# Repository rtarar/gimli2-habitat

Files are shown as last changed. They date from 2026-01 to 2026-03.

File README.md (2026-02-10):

# Gimli2 — Expedition Truck + Habitat Program

Gimli2 is an expedition-truck build program to create a durable, long-duration overland platform optimized for full-time living and remote work. The base vehicle is a Mercedes-Benz 1225 AF (NG80 chassis), being converted into a self-supported global-travel rig with an integrated habitat module (approximately 16 ft). The objective is a vehicle that can reliably handle corrugations, poor roads, and mixed climates while remaining serviceable, safe, and practical for extended international travel.

This repository documents the end-to-end systems engineering of the truck + habitat: structural/subframe integration, entry systems, cabinetry and interior construction, water/grey tanks and plumbing, thermal/heating (diesel/hydronic), and a 24V Victron-based electrical architecture with a large LiFePO₄ bank and a roof solar array (on the order of ~1.2 kW) to support off-grid living. The build is managed with disciplined governance (canonical artifacts, decision logs, and versioning) to prevent design drift across tools, vendors, and iterations—and to preserve a high-quality record suitable for future publication.

---

## What We’re Building

- **Base vehicle:** Mercedes-Benz 1225 AF (NG80 chassis)
- **Habitat module:** ~16 ft expedition habitat for full-time living + remote work
- **Primary design goals:** reliability, serviceability, off-grid autonomy, safety, and documentation completeness
- **Core systems in scope:**
  - Structure & integration (subframe, pass-through, reinforcements)
  - Electrical (24V Victron ecosystem, LiFePO₄ bank, solar, monitoring)
  - Plumbing (fresh + grey, filtration, pumps, winterization considerations)
  - Thermal (diesel/hydronic heating strategy; insulation approach)
  - Interior (cabinetry materials, mounting strategy, durability on corrugations)
  - Security & networking (as required for remote work and travel)

---

## How This Repo Is Organized

This repo is designed so newcomers can understand the project, and contributors can make changes without causing “design drift.”

- `docs/specs/` — Requirements, constraints, acceptance criteria, design targets
- `docs/architecture/` — System architecture, schematics, interface-control notes
- `docs/decisions/` — Decision log / ADR-style records (what we chose and why)
- `docs/vendor/` — Vendor comms, quotes, procurement decisions, lead times
- `cad/` — CAD exports (STEP/DXF), profiles, reference geometry
- `build-log/` — Build log entries, photos/notes, “what changed in the real world”

> The enforceable rules for how changes are proposed and recorded live in `PROJECT_CONSTITUTION.md`.

---

## Working Agreements (High Level)

- Major design choices must be recorded in the decision log before they are treated as “real.”
- Drawings and specs must carry a version and “Last updated” date when modified.
- Unknowns are explicitly marked `TBD` with an owner/action to resolve them.

---

## Habitat Floor Plan

**Key dimensions:**
- Interior: 4780mm (L) × 2280mm (W) × 2160mm (H)
- Kitchen: ~2300mm length × 600mm depth (**passenger side**)
- Floor-to-ceiling cabinets opposite kitchen (**driver side**)
- Bathroom: toilet on **driver side** (below WIN-04), shower on **passenger side**
- Entry door (DOOR-01): **passenger side**, adjacent to shower area
- Kitchen window (WIN-05): **passenger side**, in kitchen zone
- Bathroom window (WIN-04): **driver side**, above toilet
- Garage shell: wall-to-wall (2280mm), 860mm high, with exterior hatches on both sides
- U-shaped dinette with rear bench seating on garage shell top

### Top View — Day Mode (Bed Raised)

Floor Plan - Top View

### Side Elevation — Passenger Side (Looking Toward Driver)

Side Elevation View

### Layout Summary

| Element | Location | Notes |
|---|---|---|
| **Kitchen** | Passenger side | Behind bathroom, with WIN-05 window |
| **Floor-to-ceiling cabinets** | Driver side | Opposite kitchen |
| **Toilet** | Driver side (bathroom) | Below WIN-04 window |
| **Shower** | Passenger side (bathroom) | Adjacent to entry door |
| **Entry door (DOOR-01)** | Passenger side | Opens into bathroom/shower area |
| **WIN-04** | Driver side | Bathroom window above toilet |
| **WIN-05** | Passenger side | Kitchen window |
| **Bedside cabinets (lower)** | Both sides | 300mm deep × **660mm long** (ends where WIN-01/WIN-02 start) |
| **Bedside cabinets (upper)** | Both sides | 300mm deep × 2000mm long (above window level) |

### Bedside Cabinet Structure (ZONE-007)

The bedside storage cabinets are split into three vertical zones to avoid blocking the rear windows:

| Zone | Height Range | Depth | Description |
|---|---|---|---|
| **Lower** | 0–860mm | 660mm | Bulk storage, ends where windows start |
| **Window** | 860–1435mm | — | No cabinet (window clearance for WIN-01/WIN-02) |
| **Upper** | 1435–2160mm | 2000mm | Full bed length, above window level |

**Window clearance calculation:**
- WIN-01/WIN-02 centers: 1200mm from rear wall, width 1063mm
- Window rear edge: 1200 - 531.5 = **668.5mm** from rear
- Lower cabinet depth: **660mm** (8.5mm clearance from window)

### Interactive 3D Viewer

To explore the habitat in 3D, you can host this repository on GitHub Pages or view it locally.

**View Online (GitHub Pages):**
1. Go to repository **Settings** > **Pages**.
2. Select `main` branch as the source and save.
3. Your viewer will be live at: `https://rtarar.github.io/gimli2-habitat/renders/habitat_zones_3d.html`

**View Locally:**
Open the HTML file in your browser:
```bash
open renders/habitat_zones_3d.html
```

The 3D viewer includes:
- All functional zones (color-coded)
- Day/Night mode toggle (shows bed raised vs lowered)
- Wireframe view option
- Windows, doors, and hatches
- **Click zones** to highlight and identify them.

---

## Current Status (Update as Needed)

- [ ] Baseline architecture and subsystem boundaries captured
- [ ] Electrical one-line and parts list stabilized (24V Victron)
- [ ] Plumbing and tank layout finalized (fresh/grey, filtration, winterization)
- [ ] Thermal/insulation strategy selected and documented
- [ ] Entry and exterior integration decisions (steps/ladder, carriers, hatches)
- [ ] Interior cabinetry material and mounting strategy confirmed

---

## Contributing

If you want to contribute, open an issue describing:
1) the problem or improvement,
2) the affected subsystem(s),
3) the tradeoffs you see,
4) any links to relevant artifacts (specs, drawings, vendor data).

Proposed changes that impact architecture, safety, or procurement should include a decision entry in `docs/decisions/`.

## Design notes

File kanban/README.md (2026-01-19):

# Kanban Workflow

This directory manages work prioritization and tracking for the Gimli2 Habitat project.

## Board Structure

Work items flow through these stages:

```
BACKLOG → READY → IN_PROGRESS → REVIEW → DONE
```

### Stage Definitions

| Stage | Description |
|---|---|
| BACKLOG | Identified work, not yet prioritized |
| READY | Prioritized, dependencies resolved, ready to start |
| IN_PROGRESS | Actively being worked on |
| REVIEW | Work complete, awaiting validation/approval |
| DONE | Validated, approved, and archived |

## File Organization

```
kanban/
├── README.md           # This file
├── backlog.yml         # Items in BACKLOG
├── ready.yml           # Items READY to start
├── in-progress.yml     # Items IN_PROGRESS
├── review.yml          # Items in REVIEW
├── done/               # Archived completed items
│   └── YYYY-MM/        # Organized by month
└── templates/
    └── work-item.yml   # Template for new items
```

## Work Item Schema

Each work item follows this structure:

```yaml
- id: WI-001
  title: Short descriptive title
  type: requirement | design | validation | documentation
  description: |
    Detailed description of the work
  created: YYYY-MM-DD
  created_by: name
  priority: critical | high | medium | low
  dependencies:
    - WI-000  # Must complete first
  blocks:
    - WI-002  # Cannot start until this completes
  requirements:
    - REQ-001  # Related requirements
  decisions:
    - DEC-001  # Related decisions
  assigned_to: null | name
  status: backlog | ready | in_progress | review | done
  notes: |
    Additional context
```

## Rules

### Adding Items

1. New items start in BACKLOG
2. Include all known dependencies
3. Reference related requirements/decisions
4. AI agents may propose items (status: PROPOSED)

### Moving Items

1. Items move forward only (no regression without documentation)
2. Cannot move to READY if dependencies unresolved
3. Cannot move to DONE without review approval
4. Log all status changes with timestamp and reason

### Priority Definitions

| Priority | Definition |
|---|---|
| CRITICAL | Blocks all other work, must resolve immediately |
| HIGH | Important for current milestone |
| MEDIUM | Should complete this iteration |
| LOW | Nice to have, can defer |

### Dependencies

- Dependencies must be explicit
- Cannot start work with unresolved dependencies
- Circular dependencies are forbidden (see GOVERNANCE.md)
- AI agents must check dependencies before proposing actions

## Metrics (Future)

Track for continuous improvement:
- Cycle time per item type
- Blocked time
- Throughput per week
- Dependency chains length

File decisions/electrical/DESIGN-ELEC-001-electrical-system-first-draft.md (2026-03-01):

# Electrical System Design — First Draft

**ID:** DESIGN-ELEC-001
**Version:** 0.3 (Updated with alternator, heater, CPAP, Starlink decisions)
**Date:** 2026-02-28
**Status:** DRAFT — Pending Owner Review
**Resolves:** DECISIONS-ELEC-001 (Sections A–F) + REVIEW-ELEC-001 (Findings #1–#10)

---

## 0. Design Basis & Assumptions

**Design locale:** Southeast USA (primary); worldwide expedition (secondary).
**Autonomy target:** 10 days without shore power or engine charging.
**Cooking strategy:** Indoor electric when weather is poor; outdoor propane kitchen when weather permits. Load scenarios modelled as "Heavy" (all-electric cooking) and "Conservation" (propane cooking, minimal AC loads).
**Bus voltage:** 24 V DC (DECIDED 2026-02-28).
**Battery chemistry:** LiFePO4 (Victron NG series).
**Ecosystem:** Victron throughout for integration, international parts availability, and Cerbo GX monitoring.
**Generator backup:** Diesel generator in rear storage box, driver side (DECIDED 2026-02-28).
**Wiring standard:** ABYC E-11 marine-grade throughout (DECIDED 2026-02-28).
**Charge sources (4):** Solar array, alternator DC-DC, shore power, diesel generator.

---

## 1. Battery Bank (B3, B9 — DECIDED)

**Selection:** 4 × Victron Lithium NG 25.6V / 300Ah, connected in parallel.

| Parameter | Value |
|---|---|
| Nominal voltage | 25.6 V |
| Total capacity | 1,200 Ah |
| Total energy | 30.7 kWh |
| Usable energy (95% DoD) | 29.2 kWh |
| Max continuous discharge | 1,200 A (4 × 300A) |
| Dimensions per unit | 841 × 206 × 205 mm (L × H × D) |
| Weight per unit | 52 kg |
| Total battery weight | 208 kg |
| BMS required | Lynx Smart BMS NG 1000A |

### 1.1 Fitment Verification (Updated)

The original CONFLICT-001 resolution assumed 6 modules at 540 × 250 × 220 mm, totalling 300 kg. The new selection is 4 × NG 25.6V/300Ah — significantly different geometry but **92 kg lighter**.

**Proposed arrangement:** 2 × 2 stack (2 across depth, 2 high) in the Passenger-Side Kitchen Base, above the water tank toe-kick extension.

| Dimension | Required (with 25mm clearance) | Available | Status |
|---|---|---|---|
| Depth | 485 mm (2 × 205 + 3 × 25) | 600 mm | FITS |
| Height | 487 mm (2 × 206 + 3 × 25) | ~600 mm (above 200mm tank) | FITS |
| Length | 891 mm (841 + 2 × 25) | Along habitat axis | FITS |

**Mass balance impact:** 208 kg at Z ≈ +800 (forward of axle) continues to serve as counterweight to the rear water/structure mass. The 92 kg weight reduction vs. original assumption improves the overall mass budget.

**Action required:** Confirm the 891mm length along the habitat axis does not conflict with adjacent cabinetry or the water tank extension footprint.

---

## 2. Appliance Selections (Section A)

### A1 — Induction Cooktop (2-Burner)

**Recommended:** Camplux RIH602BF or equivalent 2-burner, 120V / 1800W shared power.

| Parameter | Value |
|---|---|
| Rated power | 1800 W (shared between burners) |
| Surge | ~2200 W (momentary at startup) |
| Voltage | 120 V AC / 15A circuit |
| Mounting | Built-in or countertop |

**Notes:** 1800W shared means both burners cannot run at full power simultaneously — one operates at reduced output. This is standard for RV 15A circuits. For heavy Indian cooking with two pots, expect to stagger burners or use mid-power settings. The outdoor propane kitchen handles overflow.

### A2 — Convection Microwave / Oven / Air Fryer Combo

**Status: OPEN — Research required.**

No final decision has been recorded on this appliance. Options to evaluate:

1. **Convection microwave only** (e.g., Sharp R1874T, ~1500W input) — proven RV choice, compact.
2. **Microwave + air fryer combo** (e.g., Toshiba ML2-EC10SA, Galanz GSWWA16BKSA10) — adds air-frying without a separate appliance.
3. **Dedicated air fryer + separate microwave** — better at each task but takes two slots/circuits.

**Placeholder for load table:** Using 1,500W input / 1,800W surge until model is selected.

| Parameter | Value (placeholder) |
|---|---|
| Input power | ~1,500 W |
| Surge | ~1,800 W |
| Voltage | 120 V AC / dedicated 15A circuit |

**Action required:** Owner to research combo units and decide. Key criteria: 120V operation, ≤1500W input, fits RV cutout dimensions, available internationally (or easy to replace).

### A3 — Roof Fans (× 2)

**Recommended:** MaxxFan Deluxe 7000K (with remote control + thermostat).

| Parameter | Value |
|---|---|
| Voltage | 12 V DC (requires 24V→12V converter) |
| Current draw | 0.2 A (low) to 2.66 A (max) per unit |
| Average draw (mid speed) | ~1.3 A per unit at 12V ≈ 16W each |
| Total for 2 units | ~32 W average |

### A4 — Washer

**Recommended:** Compact portable washer, shore-power only.

| Parameter | Value |
|---|---|
| NA market | 120V unit (Comfee or equivalent, ~300W) |
| International | 230V unit for European/Indian shore power |
| Operation | Shore-only (per REQ-ELEC-001 §7.2) |

**Strategy:** Carry one 120V unit for NA, or source a universal-voltage compact washer. The 230V outlet (Section F) on shore power handles international camping. This appliance is excluded from the battery load table.

### A5 — Fridge / Freezer (DECIDED)

**Selected:** Vitrifrigo SLIM250 CHR HP, Black.

| Parameter | Value |
|---|---|
| Total capacity | 250 L (two compartments: upper front-opening + lower drawer) |
| Voltage | 12/24 V DC and 115/230 V AC |
| Rated power | 75 W |
| Compressor | NextGen R600a (high performance, 3 kg lighter than standard) |
| Dimensions | 595 mm (W) × 651 mm (D) × 1,550 mm (H) |
| Weight | ~59 kg |
| Daily consumption (est.) | ~900–1,200 Wh/day (75W × 50–65% duty cycle) |

**Notes:** The SLIM250 is a significantly larger unit than the C115i originally considered. The 75W rated power with duty cycling in hot SE USA conditions could push daily consumption to ~1,200 Wh/day. This is a meaningful increase in the load table. The unit should run on 24V DC directly to avoid inverter losses. Confirm 24V DC operation from the SLIM250 specs.

### A6 — Separate Freezer

**Not required.** The SLIM250 has a dedicated lower freezer drawer compartment, providing ample frozen storage for expedition provisioning.

### A7 — Starlink (DECIDED)

**Selected:** Starlink Standard (flat dish, Gen 3).

| Parameter | Value |
|---|---|
| Active power | 50–75 W |
| Idle/standby | ~20 W |
| Daily consumption (16h active / 8h idle) | ~960–1,360 Wh |
| Voltage | Proprietary PoE, 48V from router brick |

**Notes:** Starlink is the single largest continuous DC load. Schedule Starlink sleep mode overnight to save ~160 Wh/night. The load table uses 960 Wh/day (16h active at 60W average).

### A8 — Router

**Recommended:** Pepwave MAX BR1 Pro 5G.

| Parameter | Value |
|---|---|
| Nominal power | 8 W |
| Max power | 19 W |
| Average | 12 W |
| Input | 12 V DC |
| Daily consumption | ~288 Wh |

### A9 — CPAP (DECIDED)

**Selected:** ResMed AirSense 10 (primary, with humidifier) + ResMed AirMini (travel/backup).

#### AirSense 10 (Primary — with Humidifier)

| Parameter | Value |
|---|---|
| Power supply | 24V DC / 90W rated |
| Typical power (with humidifier, no heated tube) | ~30–53 W |
| Peak power (with heated tube + humidifier) | ~70–104 W |
| Nightly consumption (8 hrs, humidifier on) | ~240–420 Wh |
| Input | 24V DC (native — matches bus voltage directly) |

#### AirMini (Travel / Backup)

| Parameter | Value |
|---|---|
| Typical power | ~6.3 W |
| Peak power | 27 W |
| Nightly consumption (8 hrs) | ~50–70 Wh |
| Input | 24V DC (native) |

**Notes:** Both units run natively on 24V DC, matching the bus voltage — no inverter needed. The AirSense 10 with humidifier is the heavier load (~240–420 Wh/night depending on heated tube setting). Use a direct 24V DC cable adapter for both. The AirMini uses waterless humidification (HumidX cartridge) and draws significantly less power, making it ideal for deep off-grid nights when power is scarce or as backup if the AirSense 10 develops issues.

**Load table impact:** Using AirSense 10 with humidifier at mid-range (~330 Wh/night) as the baseline. This is a meaningful increase from the original 72 Wh estimate (AirSense 11 without humidifier).

### A10 — UV Water Filter

**Recommended:** Viqua S2Q-P/12VDC.

| Parameter | Value |
|---|---|
| Power | 17 W |
| Flow rate | 3 GPM |
| Voltage | 12 V DC |
| Daily consumption | ~4 Wh (on-demand only) |

---

## 2B. Additional Systems (Electrical Load Inputs)

### Diesel Heater — Webasto ThermaPro 90 (DECIDED)

The habitat will use a Webasto ThermaPro 90 external diesel heater with heat exchanger, tapping into the engine coolant circuit. A future hydronic heating solution for the habitat interior will be integrated later.

| Parameter | Value |
|---|---|
| Heat output | Up to 9.1 kW |
| Fuel | Diesel (0.2–0.9 L/hr) |
| Electrical consumption | 37–83 W (operating range), 110 W max |
| Voltage | 24V DC (CONFIRMED) |
| Operating temp range | −40 to +80°C |

**Electrical impact:** When running, the ThermaPro 90 draws 37–83W from the DC bus. In cold-weather camping (heater running 12+ hrs/day), this adds 450–1,000 Wh/day to the load table. Added as a winter-use line item.

### Water Cabinet — Integrated Pump + Accumulator (DECIDED)

The water system will use a MotorCraft (or equivalent) integrated water cabinet solution combining the pump, accumulator, and associated plumbing components in a single pre-assembled unit.

**Electrical impact:** The integrated pump unit replaces the separate pump line items in the load table. Typical draw: 60W when running, intermittent duty cycle (~30 min/day total). ~30 Wh/day.

**Action required:** Confirm exact brand/model and power specifications for the water cabinet. The "MotorCraft" name did not return results — may be a different brand (Whale, Truma, Fiamma?). Please confirm.

---

## 3. Load Table (B1)

### 3.1 AC Loads (Through Inverter)

| Load | W (cont) | W (surge) | Heavy Wh/day | Conservation Wh/day |
|---|---|---|---|---|
| Induction cooktop | 1,800 | 2,200 | 2,935 | 0 |
| Convection microwave | 1,500 | 1,800 | 815 | 0 |
| Instapot | 1,000 | 1,200 | 815 | 0 |
| Blender/grinder | 500 | 1,200 | 54 | 0 |
| TV/monitor | 60 | 80 | 196 | 130 |
| Laptop charging ×2 | 130 | 130 | 565 | 424 |
| Phone/tablet charging | 30 | 30 | 98 | 65 |
| Heat pad | 60 | 60 | 130 | 65 |
| Vacuum | 400 | 600 | 65 | 43 |
| **AC subtotal (at battery, 92% inv eff)** | | | **5,674** | **728** |

### 3.2 DC Loads (Direct from Bus)

| Load | W (cont) | W (surge) | Heavy Wh/day | Conservation Wh/day |
|---|---|---|---|---|
| Fridge/freezer (SLIM250) | 45 | 75 | 1,080 | 1,080 |
| Starlink Standard | 60 | 100 | 960 | 480 |
| Pepwave BR1 Pro 5G | 12 | 19 | 288 | 288 |
| MaxxFan ×2 | 32 | 64 | 384 | 256 |
| Interior lighting (all) | 50 | 100 | 300 | 200 |
| Cabinet/drawer lights | 5 | 15 | 5 | 2 |
| Water pump (internal) | 60 | 120 | 30 | 18 |
| Water pump (stream intake) | 80 | 150 | 20 | 0 |
| UV water filter | 17 | 17 | 4 | 3 |
| Cameras ×4 | 12 | 16 | 288 | 288 |
| NVR | 10 | 15 | 240 | 240 |
| IR emitters ×6 | 12 | 18 | 120 | 120 |
| CPAP (AirSense 10 + humidifier) | 40 | 104 | 330 | 330 |
| Camera/drone/GoPro charging | 50 | 50 | 100 | 25 |
| Toothbrush/shaver charging | 10 | 10 | 20 | 10 |
| Lynx BMS + Cerbo GX | 15 | 20 | 360 | 360 |
| ThermaPro 90 diesel heater (24V) | 60 | 110 | 0 | 0 |
| *(ThermaPro winter use: add 720 Wh/day when heating 12 hrs)* | | | | |
| **DC subtotal** | | | **4,529** | **3,700** |

### 3.3 Daily Totals

| Scenario | AC (Wh) | DC (Wh) | Losses (Wh) | Total (Wh) | Total (kWh) |
|---|---|---|---|---|---|
| **Heavy cooking day** | 5,674 | 4,529 | 200 | **10,403** | **10.4** |
| **Conservation mode** | 728 | 3,700 | 200 | **4,628** | **4.6** |
| **Conservation + winter heating** | 728 | 4,420 | 200 | **5,348** | **5.3** |

**Note on v0.3 changes:** AirSense 10 with humidifier adds ~258 Wh/day vs original no-humidifier estimate (72 → 330 Wh/night). Starlink Standard retained. The SLIM250 fridge (1,080 Wh/day) remains the dominant baseline load at ~23% of conservation demand.

---

## 4. Daily Demand & Autonomy Analysis (B2)

### 4.1 Autonomy Without Solar

| Scenario | Daily demand | Battery autonomy (29.2 kWh usable) |
|---|---|---|
| Heavy cooking | 10.4 kWh | 2.8 days |
| Conservation (propane) | 4.6 kWh | 6.3 days |
| Conservation + winter heating | 5.3 kWh | 5.5 days |

### 4.2 Key Finding — 10-Day Target

With the SLIM250 fridge, Starlink Standard, and AirSense 10 with humidifier, the 10-day no-solar target requires active energy management. At 4.6 kWh/day conservation mode, pure battery provides 6.3 days.

**Realistic scenario analysis:**

1. **Even overcast days produce solar:** At just 1 peak sun hour (heavy cloud), the 2050W array produces ~1.7 kWh/day, reducing the net drain to ~2.9 kWh/day → **10.0 days autonomy**.
2. **Starlink scheduling:** Reducing Starlink to 8 hours/day saves ~480 Wh/day → brings conservation demand to ~4.1 kWh/day → **7.1 days** pure battery, **12+ days** with minimal solar.
3. **CPAP fallback:** Switching from AirSense 10 (330 Wh/night) to AirMini (60 Wh/night) saves ~270 Wh/night — significant savings for deep off-grid stretches.
4. **Driving days:** 4 hours of engine charging adds 3.2 kWh via DC-DC chargers, nearly offsetting a full conservation day.
5. **Fridge eco-mode:** If the SLIM250 duty cycle can be reduced (cooler ambient, less door opening), consumption could drop to ~800 Wh/day, saving ~280 Wh/day.

**Realistic assessment:** The system achieves 10+ days off-grid in scenarios with minimal solar (even heavy overcast). In true zero-input scenarios (dense forest canopy, no driving), expect 6–7 days. The AirMini provides a meaningful power-saving fallback for extended off-grid. A 5th battery (+7.7 kWh, +52 kg) would push pure-battery conservation to ~8.0 days. The 10-day absolute-zero-input target may warrant the 5th battery — owner decision.

**With generator (DECIDED):** The Fischer Panda 4000s Neo eliminates the autonomy concern entirely. A 4-hour generator run charges ~10 kWh, covering 2+ days of conservation-mode demand. With the 500L diesel tank, the generator provides 500+ hours of runtime — effectively unlimited electrical autonomy regardless of solar conditions. The 10-day target is comfortably met even in zero-solar scenarios.

**Recommendation:** Start with 4 batteries. The generator provides the safety net. A 5th battery is no longer needed for autonomy — only consider it if real-world data shows you want to reduce generator run frequency.

---

## 5. Inverter / Charger (B4, B5, F1)

**Recommended:** Victron MultiPlus-II 24/5000/120-95.

| Parameter | Value |
|---|---|
| Continuous output | 4,000 W |
| Surge output (5 sec) | 9,000 W |
| AC output | 120 V / 60 Hz |
| Built-in charger | 120 A @ 24V = 2,880 W from shore |
| AC input range | 90–140 V (handles weak shore power) |
| Dimensions | 627 × 350 × 150 mm |
| Weight | 29 kg |

### 5.1 Peak Load Headroom

| Scenario | Load (W) | Inverter capacity | Headroom |
|---|---|---|---|
| Realistic peak (cooking + TV + laptop) | 1,990 | 4,000 W | 2,010 W |
| Worst case (induction + microwave) | 3,300 | 4,000 W | 700 W |
| Absolute max (cooking + Instapot) | 3,500 | 4,000 W | 500 W |

### 5.2 Dual-Voltage / International Strategy (F1)

**Decision: Single inverter/charger, field-switchable.**

The MultiPlus-II can be reconfigured between 120V/60Hz and 230V/50Hz output via software (VictronConnect). For world travel:

1. **NA mode:** 120V/60Hz output, 120V shore input — standard configuration.
2. **International mode:** Reflash to 230V/50Hz output, 230V shore input.
3. **Shore inlet:** Install a dual-standard inlet with adaptor kit (NEMA 14-50 for NA, CEE17 blue 32A for international). The MultiPlus-II's wide input range handles both.

This avoids carrying two inverters and saves ~29 kg + significant cabinet space. The trade-off is that 120V NA appliances need a step-down transformer when running in 230V mode overseas, but this only matters for the cooktop and microwave (all other loads run on DC).

**Alternative (if dual simultaneous output needed):** Add a Victron Autotransformer for split-phase or step-down functionality.

### 5.3 Washer Circuit (F2)

The washer runs shore-only. Provide a dedicated 230V/16A outlet wired directly from the shore input bus, bypassing the inverter. An interlock relay ensures this outlet is only live when shore power is connected. For NA, use the MultiPlus's AC-2 output (unswitched pass-through).

### 5.4 Additional 230V Outlet (F3)

One additional 230V general outlet in the utility zone, also on the shore-only bus. Useful for hair dryers, power tools, or other occasional high-draw appliances at campsites.

---

## 6. Solar Array (B6)

### 6.1 Panel Selection

**Recommended:** 5 × 410W monocrystalline panels (generic high-quality, e.g., Trina, JA Solar, or similar).

| Parameter | Value |
|---|---|
| Panel dimensions | 1,722 × 1,134 × 30 mm |
| Weight per panel | 21.5 kg |
| Total array | 2,050 W |
| Total weight | 107.5 kg |

### 6.2 Roof Layout

Roof area: 4,750 × 2,280 mm (10.8 m²).

**Layout:** 4 panels in 2×2 portrait grid (occupying 3,444 × 2,268 mm at the forward section), plus 1 panel in landscape orientation (1,134 × 1,722 mm) offset. Remaining roof area (~1,300 × 2,280 mm at the rear) accommodates 2× MaxxFan roof vents, Starlink dish mount, and the consolidated cable penetration.

### 6.3 Solar Production by Location

| Location | Peak Sun Hours | Net Production (kWh/day) |
|---|---|---|
| SE USA (summer) | 5.5 | 9.2 |
| SE USA (winter) | 3.5 | 5.9 |
| SE USA (annual avg) | 4.5 | 7.6 |
| Northern Europe (summer) | 4.0 | 6.7 |
| Northern Europe (winter) | 1.5 | 2.5 |
| India (annual avg) | 5.0 | 8.4 |
| Overcast / cloudy | 1.0 | 1.7 |

(Net = gross × 0.82 system efficiency factor for MPPT efficiency, cable losses, temperature derating, and dust/soiling.)

### 6.4 Net Energy Balance (Updated for SLIM250 Fridge)

| Scenario | Demand | Solar | Net drain | Battery days |
|---|---|---|---|---|
| Heavy cooking, SE USA avg | 10.4 kWh | 7.6 kWh | +2.8 kWh | 10.4 days |
| Heavy cooking, no sun | 10.4 kWh | 0 | +10.4 kWh | 2.8 days |
| Conservation, SE USA avg | 4.6 kWh | 7.6 kWh | −3.0 kWh | ∞ (net charge) |
| Conservation, no sun | 4.6 kWh | 0 | +4.6 kWh | 6.3 days |
| Conservation, cloudy (1 PSH) | 4.6 kWh | 1.7 kWh | +2.9 kWh | 10.0 days |
| Conservation + winter heat, SE USA | 5.3 kWh | 7.6 kWh | −2.3 kWh | ∞ (net charge) |

**Conclusion:** In SE USA with average sun, the solar array fully covers all scenarios including winter heating. The system is solar-positive for conservation and near break-even for heavy cooking. The CPAP with humidifier adds ~258 Wh/night vs the original estimate; the AirMini backup provides a meaningful off-grid power-saving fallback. The SLIM250 fridge remains the dominant baseline load.

### 6.5 MPPT Controller

**Recommended:** Victron SmartSolar MPPT 250/100 VE.Can.

| Parameter | Value |
|---|---|
| Max PV power (at 24V) | 2,900 W (headroom for 2,050W array) |
| Max charge current | 100 A |
| Max PV Voc | 250 V |
| String config | 5S1P (cold Voc ~209V, within limit) or 2S2P + 1 |

**Preferred string configuration:** 5 panels in series (5S1P). This keeps the array current low (~13A) reducing cable losses, and the cold-weather Voc (~209V at −10°C) stays safely within the 250V controller limit. Higher voltage also improves MPPT efficiency at low light levels.

---

## 7. Alternator Charging (B10) — DECIDED

**Selected:** 2 × Victron Orion-Tr Smart 24/24-17A (isolated), wired in parallel.

| Parameter | Value |
|---|---|
| Truck alternator | 24V / 110A (CONFIRMED) |
| Per unit | 17A continuous / 400W |
| Combined output | 34A / 800W |
| Daily charge (4 hrs driving) | 3.2 kWh |

**Notes:** The truck alternator is confirmed as 24V / 110A. The 34A combined draw from the two Orion-Tr units represents ~31% of the alternator's rated capacity — well within safe continuous loading (typically 70–80% of rated output). The Orion-Tr Smart has engine-detection logic, adaptive 3-stage charging, and Bluetooth monitoring. Two units in parallel provide redundancy — if one fails, the other continues charging at 400W.

For trucks with smart alternators or Euro 6 emissions alternators, the Orion-Tr's current-limiting protects the alternator.

---

## 7B. Diesel Generator — DECIDED

**Selected:** Fischer Panda 4000s Neo PMS (AC output version).

| Parameter | Value |
|---|---|
| Continuous output | 3.0 kW (3.6 kVA) |
| Max output | 3.4 kW (4.0 kVA) |
| Voltage | 230V / 50Hz (also configurable for 120V / 60Hz) |
| Engine | Fischer Panda single-cylinder diesel, water-cooled |
| Cooling | Double-circuit freshwater heat exchanger + air-cooled radiator |
| Noise | 54 dB(A) at 7m (whisper-quiet, conversational volume) |
| Dimensions | 558 × 460 × 518 mm (L × W × H) |
| Weight (dry) | 92 kg |
| Fuel consumption | 0.6–1.2 L/hr |
| Fuel source | Tapped from main truck diesel tank |

**Location:** Rear storage box, driver side, behind rear storage. Compartment minimum: 733 × 635 × 568 mm (including service clearances and vibration mount gaps).

**Integration:** Generator AC output connects to the shore power input bus via a changeover relay. The MultiPlus-II auto-detects AC input and begins charging at up to 2,880W (120A @ 24V). Auto-start via Cerbo GX relay: triggers at 25% SOC, stops at 85% SOC.

**Installation details:** Vibration-isolated mounts (Fischer Panda OEM kit), 3mm steel reinforcement plate on box floor, marine-grade wet exhaust routed to rear/underside, fuel tap with anti-siphon valve and dedicated filter, air-cooled radiator with 12V fan for heat rejection. Compartment lined with 25mm closed-cell acoustic foam (mass-loaded vinyl backed). CO detector mandatory inside habitat.

**Charge time from generator:**

| Battery state | Time to 90% SOC |
|---|---|
| From 20% (emergency) | ~8.5 hours |
| From 50% (typical top-up) | ~4.7 hours |
| From 70% (light top-up) | ~2.4 hours |

**Why Fischer Panda:** OEM supplier for Unicat, Action Mobil, and military expedition platforms. International marine dealer network covers most port cities worldwide. Water-cooled design allows sealed compartment (no air vents for engine cooling). 54 dB at 7m is roughly 4× quieter perceived than the Onan QD 3200 alternative (72 dB at 3m).

See [DESIGN-ELEC-002-generator-selection.md](DESIGN-ELEC-002-generator-selection.md) for full comparison of evaluated models and detailed installation specifications.

---

## 8. DC Distribution (B8)

### 8.1 Bus Architecture

```
[Battery Bank 24V] → [Lynx Smart BMS NG 1000A] → [Lynx Distributor]
                                                         │
                    ┌────────────────────────────────────┤
                    │            │            │           │
              [MultiPlus-II] [MPPT 250/100] [DC-DC ×2] [DC Bus]
              (Inverter/Chgr) (Solar)       (Alternator)   │
                    │                                      │
    ┌───────────────┤                            ┌────────┤────────┐
    │               │                            │        │        │
[AC Input Bus] [AC Panel]                  [24V Loads] [24→12V ×2] [24→48V]
    │     │                                            Converters  (Starlink)
    │     │                                               │
[Shore] [Fischer Panda]                              [12V Loads]
 Power   Generator                            (Split: critical / non-critical)
         (Auto-start via Cerbo)
```

### 8.2 24V Direct Loads

Loads that can run directly on the 24V bus (or have 24V versions available): CPAP (AirSense 10 + AirMini, both native 24V), Cerbo GX, Lynx BMS, ThermaPro 90 heater (24V confirmed), some LED drivers.

### 8.3 12V Loads (via 24V→12V DC-DC Converter)

Most RV appliances run on 12V: fridge, fans, water pump, cameras, NVR, lighting, UV filter, router. Dual Victron Orion 24/12-25 (300W each) non-isolated converters provide the 12V rail with redundancy (see §13.5 and Finding #7).

| 12V Load | Draw (A at 12V) |
|---|---|
| Fridge (SLIM250) | 3.75 avg, 6.25 surge |
| MaxxFan ×2 | 2.6 avg, 5.3 max |
| Water pump | 5 avg, 10 surge |
| Lighting | 4.2 avg |
| Cameras + NVR | 1.8 |
| IR emitters | 1.0 |
| UV filter | 1.4 (intermittent) |
| Router | 1.0 |
| Misc charging | 3.0 |
| ThermaPro 90 heater | 2.5 avg, 4.6 max |
| **Total 12V** | **~24 A avg, ~38 A peak** |

**Dual converter configuration (redundancy — per REVIEW-ELEC-001 Finding #7):**

| Converter | Loads | Rating |
|---|---|---|
| **Converter A (Critical)** — Orion 24/12-25 | Fridge, water pump, interior lighting, BMS/Cerbo | 25A / 300W |
| **Converter B (Non-critical)** — Orion 24/12-25 | Fans, cameras, NVR, IR emitters, charging, heater | 25A / 300W |

If one converter fails, critical loads (fridge, pump, lights) continue on the surviving unit. Non-critical loads can be manually reconnected via a crossover switch.

### 8.4 Starlink Power (DECIDED)

Starlink Standard uses a proprietary 48V PoE feed from its router/power brick. The power brick runs on 100–240V AC. Feed from the MultiPlus-II AC output (simplest approach). A 24V→48V PoE injector could improve efficiency by avoiding inverter losses — consider as a future optimisation if Starlink power draw becomes a concern.

### 8.5 DC Fuse / Breaker Sizing

All DC circuits protected via Mega fuses (high current) or standard blade fuses (branch circuits), housed in a Lynx Distributor or Victron fuse block.

| Circuit | Fuse (A) | Wire gauge |
|---|---|---|
| Battery → BMS | 300A class-T | 4/0 AWG (short run) |
| BMS → Lynx Distributor | 300A MEGA | 4/0 AWG |
| Distributor → MultiPlus-II | 250A MEGA | 2/0 AWG |
| Distributor → MPPT | 100A MEGA | 4 AWG |
| Distributor → DC-DC (alt) | 40A | 8 AWG |
| Distributor → 12V converter | 30A | 10 AWG |
| 12V branch circuits | 5–15A blade fuses | 14–10 AWG |

---

## 9. AC Distribution (B7)

### 9.1 Branch Circuit Plan

| Circuit # | Load | Breaker | Wire | Notes |
|---|---|---|---|---|
| AC-1 | Induction cooktop | 20A / 120V | 12 AWG | Dedicated |
| AC-2 | Convection microwave | 15A / 120V | 14 AWG | Dedicated |
| AC-3 | Kitchen duplex (Instapot, blender) | 15A / 120V | 14 AWG | GFCI protected |
| AC-4 | Sitting area outlets (L + R) | 15A / 120V | 14 AWG | GFCI protected |
| AC-5 | Electronics charging drawer | 15A / 120V | 14 AWG | |
| AC-6 | Medicine cabinet + vacuum + misc | 15A / 120V | 14 AWG | |
| AC-7 | Exterior outlets (3 locations) | 20A / 120V | 12 AWG | GFCI + weatherproof |
| AC-8 | Starlink power brick | 15A / 120V | 14 AWG | Always-on (inverter output) |
| SHORE-1 | Washer (230V) | 16A / 230V | 2.5mm² | Shore-only, interlocked |
| SHORE-2 | General 230V outlet | 16A / 230V | 2.5mm² | Shore-only |

### 9.2 GFCI / AFCI Zones

All circuits serving countertop outlets, bathroom, and exterior locations are GFCI protected (per NEC for NA; equivalent RCD for international). AFCI on bedroom/sleeping area circuits if required by local code.

### 9.3 AC Panel Location

Compact RV breaker panel located adjacent to the MultiPlus-II in the Passenger Kitchen Base electrical compartment. Accessible for maintenance but not visible in the living space.

---

## 10. Switching & Control Architecture (Section C)

### C1 — Ambient Lighting Controller

**Recommended:** Victron Cerbo GX + Bluetooth LED controllers (e.g., Shelly RGBW2 or equivalent 12V RGBW LED dimmer).

The Cerbo GX provides the central hub. Individual zone LED controllers communicate via Bluetooth or Modbus for integration. Each zone has its own RGBW controller for independent dimming and colour selection (warm white / red / blue stealth modes).

**Zones:**
1. Entry + Bathroom — 1× controller
2. Kitchen + Hall — 1× controller
3. Sleeping + Sitting — 1× controller (or split into 2 for bed/sitting independence)

### C2 — Cabinet / Drawer Lighting

**Method:** Magnetic reed switches (door-triggered). Simple, reliable, no digital controller needed. Each cabinet/drawer has a surface-mount reed switch wired to a local LED strip. Power from the 12V rail via the nearest lighting zone.

### C3 — Master Ambient Switch Wiring

**Method:** Smart switch bus via Shelly or equivalent WiFi/Bluetooth relay modules at each of the 3 master switch locations (cab pass-through, main entry, bed area). Each switch sends a "scene" command to all zone controllers simultaneously.

Physical fallback: A latching relay in each zone allows the master switch to work even if the smart bus is down. Belt-and-suspenders reliability for an expedition rig.

### C4 — Bluetooth / App Control

**Platform:** VictronConnect + Cerbo GX with VRM portal. The Cerbo GX already provides app-based monitoring of all Victron equipment (battery, inverter, solar, charger). Lighting control via the smart switch modules can be accessed through a dedicated lighting app (e.g., Shelly app) or integrated via Node-RED on the Cerbo.

No KNX or complex home automation. Keep it simple and debuggable on the road.

### C5 — Bed Day/Night Mode

**Method:** Manual rocker switch at the bed position. Toggles between day-mode (under-bed ambient for sitting area) and night-mode (ceiling low-level ambient + bed reading lights active). A bed-position sensor is a nice-to-have but adds complexity and a failure point. Manual switch is more reliable for expedition use.

---

## 11. Placement & Layout (Section D)

### D1 — Kitchen Duplex Outlet

Position on the backsplash wall between the cooktop and sink, centred at countertop height (~1050mm from floor). Accessible for Instapot and blender use without cord draping over the cooktop.

### D2 — Sitting Area Outlets

One duplex each side, positioned at armrest height (~600mm from floor) on the side walls. Primary charge stations for laptops, phones, and tablets.

### D3 — Medicine Cabinet Charging

4 × USB-C outlets (PD capable) inside the medicine cabinet. USB-C handles toothbrushes, shavers, and modern chargers. No USB-A needed — all modern devices are USB-C or have USB-C cables.

### D4 — Vacuum Charging Outlet

Standard 120V outlet inside the pantry or tall storage cabinet near the entry. The vacuum lives in this cabinet, always docked and charging.

### D5 — Electronics Charging Drawer

Dedicated drawer in the cabinetry adjacent to the sitting area, fitted with a 4-outlet power strip inside. Passive ventilation via slots in the drawer rear panel (warm air rises out). Houses camera chargers, drone batteries, GoPros.

### D6 — Exterior Outlets (3 locations)

| Position | Type | Notes |
|---|---|---|
| Outdoor kitchen box (passenger) | 120V / 20A GFCI, weatherproof | Feeds outdoor blender, induction |
| Passenger rear | 120V / 20A GFCI, weatherproof | Near rear storage |
| Driver rear | 120V / 20A GFCI, weatherproof | Near tool/grill access |

All exterior outlets on a dedicated circuit (AC-7) with in-use weatherproof covers (bubble type).

### D7 — Shore Power Inlet

**Side:** Passenger side (same side as electrical compartment — shortest cable run to MultiPlus-II).
**Connector:** Combination inlet box with NEMA 14-50 (NA, 50A) and CEE17 blue (international, 32A). Adaptor cables for smaller connections (30A TT-30, standard 15A).

### D8 — Roof Penetration & Conduit

Single consolidated roof penetration near the rear of the solar array zone. Uses a marine-grade deck gland or Renogy entry plate for multiple cable pass-throughs (solar, Starlink). Conduit routes internally along the ceiling channel to the battery/electrical zone in the kitchen base.

---

## 12. Exterior Lighting (Section E)

### E1/E2 — Rock Lights

**Recommended:** 6 × RGBW LED rock lights (e.g., Sunpie or Xprite RGBW).

| Position | Count |
|---|---|
| Front (L + R) | 2 |
| Mid (L + R) | 2 |
| Rear (L + R) | 2 |

Built-in blue mode via RGBW controller. Single Bluetooth RGBW controller for all 6 lights, mounted in the DC distribution area. Manual on/off via a dedicated rocker switch + app control for colour selection.

### E3 — Front Security Floods

**Recommended:** 4 × round LED flood lamps (retro-style, per REQ-ELEC-001). Each 20–30W, warm white. Mounted on the front face of the habitat shell, 2 per side of centre.

### E4 — Side Floods

2 × high-mount LED floods (1 per side), mounted on the upper habitat GRP wall using non-penetrating adhesive mounts or bracket-to-extrusion clamps. Each 30–50W.

### E5 — Rear Flood

1 × LED flood bar mounted on the rear wall or box lid hinge support. 40–60W, covers rear perimeter.

### E6 — IR Emitters

6 × 850nm IR LED emitters positioned to cover the camera FOVs at each perimeter position. Each ~2W. Wired into the security circuit (always powered when security mode is active).

### E7 — Awning Light

Hardwired 12V connection point at the awning mounting rail. A waterproof 2-pin plug allows the awning light (user's choice of LED strip or fixture) to connect without permanent installation.

### Exterior Lighting Control

All exterior lights controlled via a dedicated rocker switch panel near the main entry door:

| Switch | Lights |
|---|---|
| Rock lights | All 6 (RGBW controller) |
| Security floods | All front, side, rear floods |
| IR night vision | All IR emitters |
| Awning | Awning light |

A "full perimeter" master button activates floods + IR simultaneously.

---

## 13. Expedition Hardening (per REVIEW-ELEC-001)

The following measures are adopted from the expedition manufacturer review to bring this design to production-grade standards.

### 13.1 Wiring Construction Standard — ABYC E-11 Marine Grade (Finding #3)

All electrical wiring in the habitat adopts the ABYC E-11 marine electrical standard:

| Requirement | Specification |
|---|---|
| Wire type | Tinned copper, marine-grade stranded, XLPE or TXL insulation rated 105°C minimum |
| Terminations | Adhesive-lined heat-shrink crimp terminals only. No bare crimps, no twist-and-tape. |
| Connectors | Deutsch DT/DTP series (IP67, vibration-rated) for all multi-pin connections. No Molex or spade terminals in vibration-exposed locations. |
| Loom construction | Adel clamps (cushioned P-clips) at max 300mm intervals. No cable ties as primary restraint. Split corrugated conduit or woven loom tape for protection. |
| Labelling | Every wire labelled at both ends with permanent heat-shrink labels (Brady or equivalent). |

### 13.2 Galvanic Isolator (Finding #4)

**Added:** Victron VDI-32 Galvanic Isolator installed in series with the shore power ground conductor at the inlet. Blocks low-voltage DC galvanic currents between chassis and international shore power grounds while passing AC fault currents for safety. Weight: 0.5 kg, cost: ~$100.

### 13.3 Battery Thermal Management (Finding #5)

The Victron NG LFP batteries cannot charge below 5°C (BMS lockout). The following measures ensure cold-climate operation:

| Measure | Detail |
|---|---|
| Insulated compartment | 25mm closed-cell foam on all six sides of the battery bay |
| Heating pads | 4× self-regulating 24V heating pads (one per battery), ~20W each = 80W total when active |
| BMS integration | Lynx Smart BMS NG has a dedicated heating relay output — pads activate automatically based on battery temperature sensor |
| Passive warming | Diesel heater coolant loop routed near (not through) battery compartment for ambient warming |

### 13.4 Surge Protection (Finding #6)

| Location | Device | Purpose |
|---|---|---|
| Solar input (before MPPT) | Type 2 SPD (e.g., Victron SPD Kit) | Lightning-induced surges from rooftop array |
| Shore power input | Type 2 SPD on AC input | Voltage spikes from international shore power |
| DC bus (after distributor) | DC SPD | Transient protection for sensitive electronics |

Total cost: ~$200–400. Weight: negligible (~1 kg total).

### 13.5 Inverter Redundancy (Finding #2)

**Decision:** Carry a pre-wired spare MultiPlus-II 24/5000 in storage. The spare has a pre-made cable harness (battery leads, AC output leads) with labelled connectors for rapid field swap. Estimated swap time: 30–45 minutes with basic tools. Weight: 29 kg (stored). Cost: ~$2,500.

### 13.6 Solar Panel Mounting (Finding #8)

| Requirement | Specification |
|---|---|
| Mount type | Z-bracket or L-bracket with rubber isolation pads (vibration dampening) |
| Attachment | Through-bolted to roof rails or structural aluminium extrusion. No adhesive-only mounting. |
| Air gap | 25–50mm between panel and roof for cooling (panel efficiency drops ~0.4%/°C above 25°C) |
| Edge protection | Sacrificial aluminium angle around panel perimeter to absorb branch impacts |
| Rating | Must survive continuous corrugated road vibration and 130+ km/h wind loads |

### 13.7 Load Shedding / Critical Load Priority (Finding #9)

The Cerbo GX controls programmable relay outputs to disconnect load groups based on battery SOC:

| SOC Threshold | Action |
|---|---|
| < 40% | **Warning** — Cerbo GX alert to VRM app + audible buzzer |
| < 30% | **Shed Tier 1** — Disconnect non-essential AC loads (TV, charging drawer, vacuum) via relay |
| < 20% | **Shed Tier 2** — Disconnect Starlink, exterior lighting, non-critical 12V converter |
| < 15% | **Shed Tier 3** — Only critical loads remain: fridge, water pump, interior emergency lighting, cameras, BMS |
| < 10% | **Generator auto-start** (if enabled) — Fischer Panda starts automatically |
| < 5% | **BMS disconnect** — Lynx Smart BMS disconnects all loads to protect batteries |

**Emergency lighting:** A dedicated 12V LED strip in the entry and bathroom wired on the last-disconnect circuit. Always on until the BMS physically opens the contactor.

### 13.8 Shore Power Cable Storage (Finding #10)

Dedicated exterior storage compartment (or section of the rear garage bay) for shore power cables and adaptors. Cable inventory for world travel:

| Cable / Adaptor | Region |
|---|---|
| NEMA 14-50 (50A) shore cord | North America |
| NEMA TT-30 (30A) adaptor | NA campgrounds |
| CEE17 blue 32A cord | Europe |
| CEE17 blue 16A adaptor | EU campgrounds |
| Indian 3-pin adaptor | India / South Asia |
| AU/NZ adaptor | Australia / New Zealand |
| South African 3-pin adaptor | Southern Africa |
| 25m extension cord | Universal |

All cables labelled with country/standard. Hook-and-coil storage to prevent tangles.

---

## 14. System Weight Budget

| Component | Weight (kg) | Location |
|---|---|---|
| **Core Electrical** | | |
| Batteries (4× NG 25.6V/300Ah) | 208.0 | Passenger kitchen base |
| Lynx Smart BMS NG 1000A | 5.0 | Adjacent to batteries |
| MultiPlus-II 24/5000 (active) | 29.0 | Passenger kitchen base |
| MultiPlus-II 24/5000 (spare) | 29.0 | Stored (garage/under bench) |
| SmartSolar MPPT 250/100 | 4.5 | Passenger kitchen base |
| Orion-Tr Smart DC-DC ×2 (alternator) | 3.4 | Passenger kitchen base |
| Orion 24/12-25 ×2 (12V converters) | 2.0 | DC distribution area |
| Cerbo GX + GX Touch 50 | 1.5 | Accessible panel |
| **Solar** | | |
| Solar panels (5× 410W) | 107.5 | Roof |
| Solar mounting (Z-brackets, edge guards) | 5.0 | Roof |
| **Generator** | | |
| Fischer Panda 4000s Neo PMS | 92.0 | Rear storage box, driver side |
| Generator mounting (plate, isolators) | 8.0 | Rear storage box |
| Generator cooling (radiator, hoses, fluid) | 5.0 | Rear storage box |
| Generator exhaust system | 3.0 | Rear underside |
| Generator fuel lines + filter | 2.0 | Rear to main tank |
| Generator wiring + changeover relay | 2.0 | Rear to passenger side |
| Generator compartment acoustic treatment | 3.0 | Rear storage box |
| **Expedition Hardening** | | |
| Galvanic isolator (VDI-32) | 0.5 | Shore inlet |
| Battery heating pads (×4) + insulation | 2.0 | Battery compartment |
| Surge protection (SPDs ×3) | 1.0 | Solar/shore/DC bus |
| **Distribution & Wiring** | | |
| Cabling (marine-grade tinned copper) | 28.0 | Throughout |
| DC distribution (Lynx Distributor, busbars, fuses) | 8.0 | Passenger kitchen base |
| AC distribution (breakers, panel) | 5.0 | Passenger kitchen base |
| Misc (Deutsch connectors, Adel clamps, conduit) | 12.0 | Throughout |
| **TOTAL** | **~566** | |

**Weight breakdown by zone:**

| Zone | Weight (kg) |
|---|---|
| Passenger kitchen base (batteries + electronics) | ~293 |
| Roof (solar) | ~113 |
| Rear driver side (generator) | ~115 |
| Distributed (cabling, distribution) | ~45 |

---

## 15. Full Bill of Materials

### Victron Components

| Item | Model | Qty | Role |
|---|---|---|---|
| Battery | Victron Lithium NG 25.6V/300Ah | 4 | Energy storage |
| BMS | Lynx Smart BMS NG 1000A | 1 | Battery management |
| Inverter/Charger (active) | MultiPlus-II 24/5000/120-95 | 1 | AC power + shore charging |
| Inverter/Charger (spare) | MultiPlus-II 24/5000/120-95 | 1 | Pre-wired field-swap spare |
| Solar MPPT | SmartSolar MPPT 250/100 VE.Can | 1 | Solar charge control |
| DC-DC Charger (alternator) | Orion-Tr Smart 24/24-17A (isolated) | 2 | Alternator charging |
| 24→12V Converter (critical loads) | Orion 24/12-25 (non-isolated) | 1 | Fridge, pump, lights |
| 24→12V Converter (non-critical loads) | Orion 24/12-25 (non-isolated) | 1 | Fans, cameras, charging |
| DC Distribution | Lynx Distributor | 1 | Main DC bus |
| System Monitor | Cerbo GX + GX Touch 50 | 1 | Central monitoring + app + auto-start |
| Galvanic Isolator | VDI-32 | 1 | Shore power ground protection |
| Solar Panel | 410W Monocrystalline (Trina/JA Solar) | 5 | Solar generation |

### Non-Victron Components

| Item | Model | Qty | Role |
|---|---|---|---|
| Generator | Fischer Panda 4000s Neo PMS | 1 | Backup charging (3.0–3.4 kW diesel) |
| Surge protector (solar) | Type 2 SPD (Phoenix Contact or equiv.) | 1 | Lightning/surge on PV input |
| Surge protector (shore) | Type 2 SPD | 1 | Shore power transient protection |
| Surge protector (DC bus) | DC SPD | 1 | Battery bus transient protection |
| Battery heating pads | 24V self-regulating, 20W each | 4 | Cold-climate charge enable |
| CO detector | Marine-rated CO alarm | 1 | Generator compartment safety |

---

## 16. Decisions Made This Session (2026-02-28)

| # | Decision | Resolution |
|---|---|---|
| B3 | Battery bank size | 4 × Victron NG 25.6V/300Ah = 1,200 Ah / 30.7 kWh |
| B9 | Bus voltage | 24 V DC |
| B10 | Truck alternator | 24V / 110A confirmed — Orion-Tr Smart 24/24-17A ×2 validated |
| — | Generator | Fischer Panda 4000s Neo PMS, rear storage box driver side |
| — | Wiring standard | ABYC E-11 marine-grade throughout |
| — | Galvanic isolator | Victron VDI-32 on shore power ground |
| — | Battery thermal | Heating pads + insulated compartment |
| — | Surge protection | SPDs on solar, shore, DC bus |
| — | Inverter redundancy | Carry pre-wired spare MultiPlus-II |
| — | 12V converter redundancy | Dual Orion 24/12-25 (critical/non-critical split) |
| — | Load shedding | Cerbo GX relay groups with SOC thresholds |
| — | Solar mounting | Vibration-rated Z-bracket with edge guards |
| — | ThermaPro 90 voltage | 24V version confirmed |
| A7 | Starlink | Starlink Standard (flat dish Gen 3, 50–75W, 48V PoE) |
| A9 | CPAP | AirSense 10 with humidifier (primary) + AirMini (travel/backup) |

## 17. Remaining Open Items

*Items resolved in v0.3: ~~#2 Alternator voltage~~ (24V/110A confirmed), ~~#5 ThermaPro 90 voltage~~ (24V confirmed), ~~#7 CPAP~~ (AirSense 10 + humidifier + AirMini), ~~#9 Starlink model~~ (Standard selected).*

| # | Item | Impact | Urgency |
|---|---|---|---|
| 1 | Confirm 891mm battery length fits kitchen base layout along habitat axis | Fitment | HIGH |
| 2 | **Research convection microwave / air fryer combo** — no decision recorded yet | Appliance selection (A2) | HIGH |
| 3 | **Confirm water cabinet brand/model** — "MotorCraft" not found; clarify exact product | Plumbing/electrical interface | MEDIUM |
| 4 | Verify SLIM250 actual daily consumption (75W rated; duty cycle TBD) | Load table accuracy | MEDIUM |
| 5 | Select specific exterior light fixtures | Mounting details | LOW |
| 6 | Confirm washer voltage strategy (single 120V unit or dual) | Shore circuit | LOW |
| 7 | Review smart switch platform preference (Shelly, ESP32, other) | Controls | MEDIUM |
| 8 | Define hydronic heating distribution plan for habitat interior (future, ties to ThermoPro 90) | HVAC design | LOW (future phase) |
| 9 | Confirm Fischer Panda cooling method: standalone radiator vs auxiliary truck cooling | Generator install | MEDIUM |
| 10 | Decide generator auto-start via Cerbo (yes/no) | Convenience vs complexity | LOW |

---

## 18. Related Files

- [REQ-ELEC-001-electrical-requirements.md](REQ-ELEC-001-electrical-requirements.md) — Full requirements
- [DECISIONS-ELEC-001-open-decisions.md](DECISIONS-ELEC-001-open-decisions.md) — Decision tracker
- [DESIGN-ELEC-002-generator-selection.md](DESIGN-ELEC-002-generator-selection.md) — Generator selection + installation details
- [REVIEW-ELEC-001-expedition-manufacturer-perspective.md](REVIEW-ELEC-001-expedition-manufacturer-perspective.md) — Expedition review (Unicat/Bliss Mobil/EarthRoamer perspective)
- [PLAN-electrical-layout.md](PLAN-electrical-layout.md) — Battery + inverter placement
- [CONFLICT-001-battery-fitment.md](../conflicts/CONFLICT-001-battery-fitment.md) — Battery fitment resolution
- [CONFLICT-002-water-tank-fitment.md](../conflicts/CONFLICT-002-water-tank-fitment.md) — Water tank resolution

---

*v0.1 generated 2026-02-28. v0.2 updated same day with generator decision (Fischer Panda 4000s Neo), expedition hardening measures (ABYC E-11 wiring, galvanic isolation, battery thermal, surge protection, inverter/converter redundancy, load shedding, solar mounting). v0.3 updated same day with: truck alternator confirmed 24V/110A, ThermoPro 90 confirmed 24V, CPAP decided (AirSense 10 + humidifier primary + AirMini travel/backup), Starlink Standard selected. Load table and autonomy recalculated (CPAP humidifier adds ~258 Wh/night). Open items reduced from 14 to 10. All calculations verified programmatically. Wiring gauges and fuse sizes are preliminary — final validation required during detailed electrical engineering.*

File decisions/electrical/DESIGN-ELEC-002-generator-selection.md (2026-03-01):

# Generator Selection & Installation — Gimli2 Habitat

**ID:** DESIGN-ELEC-002
**Date:** 2026-02-28
**Status:** DRAFT — Pending Owner Review
**Resolves:** REVIEW-ELEC-001 Finding #1 (No backup charge source)
**Location:** Rear storage box area, driver side, behind rear storage

---

## 1. Sizing — How Big Does It Need to Be?

### 1.1 What the Generator Must Cover

The generator serves two roles — they have very different power requirements:

**Role A — Battery bank charging (primary use, 90% of runtime):**
The generator feeds the MultiPlus-II's built-in charger, which draws up to 2,880W from shore/generator AC input (120A × 24V). This is the main use case: park in jungle, run the generator for 3–4 hours, top up the batteries, shut down.

**Role B — Simultaneous charging + light AC loads:**
While charging batteries, you might also want to run the fridge on AC, charge laptops, and run lighting. This adds ~500W on top of the charger load.

| Use Case | Power Required |
|---|---|
| Battery charging only (MultiPlus charger) | 2,880 W |
| Charging + light AC loads | ~3,400 W |
| Charging + cooking (induction) | ~4,700 W (unlikely use case) |

### 1.2 Recommended Generator Size

**Minimum: 3.0 kW continuous.**
**Sweet spot: 3.5–4.0 kW continuous.**

At 3.5 kW, the generator comfortably runs the MultiPlus charger at full rate while handling background AC loads. You'd never need to cook on the generator (that's what the propane outdoor kitchen is for), so the 4.7 kW cooking scenario is irrelevant.

A 3.5 kW generator charging the 30.7 kWh battery bank at ~2.5 kW net (accounting for charger efficiency):

| Battery State | Charge Time to 90% |
|---|---|
| From 20% (emergency) | ~8.5 hours |
| From 50% (typical top-up) | ~4.7 hours |
| From 70% (light top-up) | ~2.4 hours |

---

## 2. Generator Comparison

### 2.1 The Contenders

I've evaluated five generators across two categories: purpose-built vehicle/marine units (premium, whisper-quiet) and conventional RV generators (proven, more affordable).

---

#### TIER 1 — Premium Whisper-Quiet (Expedition Grade)

**A. Fischer Panda Panda 4000s Neo PMS**

| Parameter | Value |
|---|---|
| Continuous output | 3.0 kW (3.6 kVA) |
| Max output | 3.4 kW (4.0 kVA) |
| Voltage | 230V / 50Hz (also available 120V / 60Hz) |
| Engine | Fischer Panda single-cylinder diesel, water-cooled |
| Cooling | Double-circuit freshwater heat exchanger |
| Noise | **54 dB(A) at 7m** |
| Dimensions | 558 × 460 × 518 mm (L × W × H) |
| Weight (dry) | **92 kg** |
| Fuel consumption | 0.6–1.2 L/hr |
| Key feature | "Supersilenced" — fully encapsulated, vibration-isolated |

**Verdict:** The gold standard for expedition vehicles. This is what Unicat specs. Water-cooled means no air vents needed in the compartment. 54 dB at 7m is conversational volume — you can run it at a campsite without annoying neighbours. The 230V output works directly with the MultiPlus-II in international mode; for NA, the MultiPlus accepts 120V or 230V input.

---

**B. Fischer Panda AGT-DC 4000 24V**

| Parameter | Value |
|---|---|
| Continuous output | 3.2 kW DC |
| Max output | 4.0 kW DC |
| Output | **24V DC direct** (no inverter/charger needed!) |
| Engine | Kubota diesel, water-cooled, variable speed |
| Noise | **54 dB(A) at 7m** |
| Dimensions | ~550 × 450 × 520 mm (estimated) |
| Weight (dry) | **90–142 kg** (depends on configuration) |
| Fuel consumption | 0.5–1.0 L/hr |
| Key feature | DC output charges batteries directly, bypassing the inverter/charger entirely |

**Verdict:** The most elegant solution for a 24V battery bank. The AGT-DC outputs 24V DC directly to the battery bus, eliminating the AC→charger conversion step. Higher efficiency, simpler integration, and the generator's variable-speed controller manages the charge profile. However, it's more expensive and niche — harder to find parts internationally. The Victron Lynx BMS would need to coordinate with the AGT's charge controller.

---

**C. WhisperPower Piccolo 4**

| Parameter | Value |
|---|---|
| Continuous output | 3.5 kW |
| Voltage | 120V or 230V options |
| Noise | **< 55 dB(A)** |
| Weight | **68 kg (150 lbs)** |
| Key feature | Lightest in class, compact diesel |

**Verdict:** Excellent weight-to-power ratio. 68 kg is significantly lighter than the Fischer Panda (92 kg). Similar noise levels. Good choice if weight is the primary concern. WhisperPower has a solid marine dealer network but less expedition-vehicle presence than Fischer Panda.

---

#### TIER 2 — Proven RV Generators (Value)

**D. Cummins Onan QD 3200**

| Parameter | Value |
|---|---|
| Continuous output | 3.2 kW |
| Voltage | 120V / 60Hz |
| Engine | 347cc single-cylinder diesel, air-cooled |
| Noise | **72 dB(A) at 3m** (~60 dB(A) at 50ft — meets National Park requirements) |
| Dimensions | 767 × 440 × 457 mm (L × W × H) |
| Weight | **93 kg (205 lbs)** |
| Fuel consumption | 0.3–0.7 L/hr |
| Key feature | Industry standard RV generator, massive dealer/parts network, runs from vehicle fuel tank |

**Verdict:** The workhorse choice. Every RV dealer in North America stocks Onan parts. Air-cooled means simpler installation (no coolant plumbing) but louder than water-cooled units. At 72 dB at 3m it's noticeably louder than the Fischer Panda (54 dB at 7m — that's roughly 4× louder perceived). 120V only — needs the MultiPlus to be in NA mode, or a step-up transformer internationally.

---

**E. Dometic TEC 29** (Petrol — included for reference)

| Parameter | Value |
|---|---|
| Continuous output | 2.6 kW |
| Voltage | 230V / 50Hz |
| Engine | Honda GX160 **petrol** (not diesel) |
| Noise | **54 dB(A) at 7m** |
| Dimensions | 480 × 385 × 290 mm |
| Weight | **44 kg** |
| Key feature | Extremely compact, under-floor mounting, lightest option |

**Verdict:** The lightest and most compact option by far at only 44 kg. However, it runs on **petrol, not diesel** — meaning you'd need to carry a separate fuel supply. For an expedition truck running diesel everywhere, this is a significant logistics downside. The 2.6 kW output is also marginal for the MultiPlus charger at full rate. Included for completeness but not recommended for a diesel expedition rig.

---

### 2.2 Comparison Matrix

| Feature | Fischer Panda 4000s Neo | Fischer Panda AGT-DC 4000 | WhisperPower Piccolo 4 | Onan QD 3200 | Dometic TEC 29 |
|---|---|---|---|---|---|
| **Output** | 3.0–3.4 kW AC | 3.2–4.0 kW DC | 3.5 kW AC | 3.2 kW AC | 2.6 kW AC |
| **Fuel** | Diesel | Diesel | Diesel | Diesel | **Petrol** |
| **Cooling** | Water | Water | Water | **Air** | Air |
| **Noise (7m)** | 54 dB(A) | 54 dB(A) | <55 dB(A) | ~62 dB(A)* | 54 dB(A) |
| **Weight** | 92 kg | 90–142 kg | **68 kg** | 93 kg | **44 kg** |
| **Dimensions (LWH mm)** | 558×460×518 | ~550×450×520 | ~500×400×480 | 767×440×457 | 480×385×290 |
| **Fuel from main tank** | Yes | Yes | Yes | Yes | **No (petrol)** |
| **International parts** | Good (marine network) | Niche | Good (marine) | **Excellent (NA)** | Good (EU) |
| **Integration with 24V bus** | Via MultiPlus charger | **Direct DC — best** | Via MultiPlus charger | Via MultiPlus charger | Via MultiPlus charger |
| **Vibration isolation** | Excellent | Excellent | Good | Good | Good |
| **Est. price** | $8,000–12,000 | $10,000–15,000 | $6,000–9,000 | **$4,000–5,000** | $3,000–4,000 |

*Onan noise estimated at 7m from the 3m spec using inverse-square law.

---

## 3. Recommendation

### Primary Recommendation: Fischer Panda 4000s Neo PMS

**Why:**

1. **Whisper-quiet at 54 dB.** You can run this at a campsite, in a national park, or at 2am in a parking lot without drawing attention. The Onan at 72 dB is roughly 4× louder to the human ear.

2. **Water-cooled = sealed compartment.** No air vents needed in the storage box — the heat exchanger rejects heat through coolant. This keeps dust, rain, and insects out of the generator compartment.

3. **Diesel from the main tank.** One fuel system for the truck, heater, and generator. No carrying petrol.

4. **Right-sized at 3.0–3.4 kW.** Covers the MultiPlus charger at full rate with a little headroom.

5. **Expedition pedigree.** Fischer Panda is the OEM generator supplier for Unicat, Action Mobil, and numerous military expedition platforms. International marine dealer network means you can get service in most port cities worldwide.

**Trade-offs:** It's the second-heaviest option at 92 kg (vs 68 kg for the WhisperPower Piccolo 4), and the most expensive at $8,000–12,000. The water-cooling system adds plumbing complexity (coolant loop, raw-water intake or air-cooled radiator for vehicle installation).

### Alternative: WhisperPower Piccolo 4

If weight is critical (24 kg lighter) and budget matters, the Piccolo 4 delivers similar performance and noise levels at lower cost. It's a legitimate choice — just less proven in the expedition vehicle world than Fischer Panda.

### Budget Alternative: Cummins Onan QD 3200

If you're starting in North America and the noise difference is acceptable, the Onan is half the price with the best parts network on the continent. Consider this if the rig will spend most of its life in NA campgrounds where generator hours are common.

---

## 4. Installation — Rear Storage Box, Driver Side

### 4.1 Space Requirements

The Fischer Panda 4000s Neo needs 558 × 460 × 518 mm plus service clearances:

| Requirement | Dimension |
|---|---|
| Generator footprint | 558 × 460 mm |
| Service clearance (one side) | +150 mm |
| Exhaust routing | +100 mm rear |
| Vibration mount clearance | +25 mm all sides |
| **Total compartment minimum** | **733 × 635 × 568 mm** |

### 4.2 Mounting

1. **Vibration isolation mounts.** Fischer Panda supplies their own isolation mount kit. The generator bolts to 4× rubber-isolated mounting studs secured to a steel plate welded or bolted to the storage box floor. This is critical — diesel generator vibration will destroy the GRP shell and cabinetry if hard-mounted.

2. **Weight reinforcement.** 92 kg concentrated in the rear storage box needs structural reinforcement of the box floor. A 3mm steel plate spanning the full compartment width distributes the load to the chassis rails.

3. **Levelling.** The generator must remain within 15° of level for oil lubrication. For an expedition vehicle traversing side slopes, this is usually fine — but confirm the storage box mounting doesn't compound the angle.

### 4.3 Exhaust

1. **Route to rear/underside.** Exhaust pipe exits through the floor or rear of the storage box, pointing down and away from the cabin air intakes.

2. **Marine-grade wet exhaust** (if water-cooled exhaust option selected) — mixes cooling water with exhaust for further noise reduction.

3. **Spark arrestor / rain cap** at the exit point.

4. **High-temperature insulation** on all exhaust routing inside the compartment (fibreglass wrap or ceramic sleeve).

### 4.4 Fuel Supply

1. **Tap from main diesel tank.** A T-fitting on the truck's fuel supply line feeds the generator through its own fuel filter and shutoff valve.

2. **Return line** back to the main tank (diesel generators return unused fuel).

3. **Anti-siphon valve** to prevent fuel draining if the generator is below the tank level.

4. **Fuel filter** — separate from the truck's filters, easily accessible for service.

### 4.5 Cooling (Water-Cooled Generator)

Two options for heat rejection:

**Option A — Keel cooler / air-cooled radiator (RECOMMENDED):**
A compact air-cooled radiator (similar to an intercooler core) mounted behind the storage box with a 12V electric fan. The generator's coolant loop circulates through this radiator. No raw water intake needed — fully self-contained.

**Option B — Raw water cooling (marine style):**
Only relevant if the rig will be parked near water. Not practical for a land vehicle. Reject this option.

### 4.6 Electrical Integration

```
[Generator AC Output] → [Shore Power Inlet Bus] → [MultiPlus-II AC Input]
                              ↑
                        [Shore Power Cord]
                        (when on shore power)
```

The generator connects to the same AC input bus as shore power, through a changeover relay or the MultiPlus-II's built-in transfer switch. The MultiPlus automatically detects AC input and begins charging.

**Auto-start option:** Wire the generator's start/stop to a Cerbo GX relay output. The Cerbo can trigger generator start when battery SOC drops below a threshold (e.g., 25%) and stop when it reaches a target (e.g., 85%). This is a standard Victron feature — no custom logic needed.

### 4.7 Ventilation

Even though the generator is water-cooled (no large air intake needed for engine cooling), the compartment still needs:

1. **Combustion air intake** — small louvred vent (100 × 200 mm) in the compartment wall or floor.
2. **Heat soak ventilation** — passive vents at top and bottom of compartment to prevent heat buildup when the generator is off in hot climates.
3. **CO detection** — mandatory carbon monoxide detector inside the habitat, near the generator compartment wall.

### 4.8 Soundproofing (Belt and Suspenders)

The Fischer Panda is already supersilenced at 54 dB. For additional stealth:

1. **Line the compartment** with 25mm closed-cell acoustic foam (mass-loaded vinyl backed) on all interior surfaces.
2. **Seal all gaps** — sound leaks through the smallest opening. Weather-strip the access door.
3. **Duct the air intake** through a baffled path to attenuate intake noise.

Target: **< 50 dB(A) at 7m** with compartment treatment. This is quieter than a typical conversation.

---

## 5. Mass Balance Impact

| Item | Weight (kg) | Position |
|---|---|---|
| Generator (Fischer Panda 4000s Neo) | 92 | Rear driver side |
| Mounting plate + isolators | 8 | Rear driver side |
| Coolant system (radiator, hoses, fluid) | 5 | Rear driver side |
| Fuel lines + filter | 2 | Rear |
| Exhaust system | 3 | Rear |
| Wiring + changeover relay | 2 | Rear to passenger side |
| Acoustic treatment | 3 | Rear driver side |
| **TOTAL** | **115 kg** | **Rear driver side** |

**Mass balance concern:** 115 kg added to the rear driver side compounds the existing rear-heavy tendency (water tank, diesel tank). However, the batteries (208 kg) are forward of the axle on the passenger side, providing significant counterbalance. The generator weight is comparable to a passenger — manageable but worth validating in the overall mass balance model.

---

## 6. Operational Scenarios

### Scenario A — Jungle / Zero Solar (Primary Use Case)

Battery at 40% after 4 days in dense canopy. Run generator for 4 hours in the morning → charges ~10 kWh → battery back to ~75%. Repeat every 3–4 days. Fuel cost: ~4L diesel = negligible.

### Scenario B — Emergency / Breakdown

Truck broken down, can't drive, no sun. Generator provides indefinite autonomy at ~1L/hr. With a 500L diesel tank, that's 500+ hours of generator runtime — months of power.

### Scenario C — Winter Heating + Charging

Run generator 2–3 hours/day to supplement solar shortfall in Northern European winter. The ThermaPro 90 heater runs on diesel anyway, so the generator just adds electrical charging capacity.

### Scenario D — Shore Power Substitute

At a campsite with no power hookups (common in Africa, South America, remote Asia). Run generator for 3–4 hours to do laundry (washer), charge batteries, and run any shore-only loads.

---

## 7. Owner Decisions Required

| # | Decision | Options | Impact |
|---|---|---|---|
| 1 | **Generator brand/model** | Fischer Panda 4000s Neo (recommended) / WhisperPower Piccolo 4 / Onan QD 3200 | Cost, weight, noise |
| 2 | **AC vs DC generator** | AC via MultiPlus (simpler) / DC direct to bus (Fischer Panda AGT-DC, more efficient) | Integration complexity |
| 3 | **Auto-start via Cerbo GX?** | Yes (hands-off) / No (manual start only) | Convenience vs. complexity |
| 4 | **Cooling method** | Air-cooled radiator (self-contained, recommended) / Auxiliary from truck cooling | Plumbing complexity |
| 5 | **Acoustic treatment level** | Standard (Fischer Panda enclosure only, 54 dB) / Enhanced (compartment treatment, <50 dB) | Cost, weight |

---

## 8. Related Files

- [DESIGN-ELEC-001-electrical-system-first-draft.md](DESIGN-ELEC-001-electrical-system-first-draft.md) — Main electrical design
- [REVIEW-ELEC-001-expedition-manufacturer-perspective.md](REVIEW-ELEC-001-expedition-manufacturer-perspective.md) — Expedition review (Finding #1)

---

*Generator sizing based on Gimli2 load table (DESIGN-ELEC-001 §3). Specifications sourced from manufacturer published data. Prices are approximate market estimates and vary by region and dealer.*

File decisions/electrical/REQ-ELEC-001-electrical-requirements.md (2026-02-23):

# Electrical Requirements — Gimli2 Habitat + Truck

**ID:** REQ-ELEC-001
**Version:** 0.1
**Date:** 2026-02-23
**Status:** ACTIVE — pending load calculations and open decisions (see DECISIONS-ELEC-001)

---

## 0. Guiding Principles (Locked)

- **Off-grid first:** All core systems operate on battery + inverter without shore power. Exception: washer is shore-only.
- **Simplicity bias:** Avoid unnecessary wiring complexity. Battery-operated lights acceptable in cab and selectively elsewhere.
- **Lighting taxonomy:** Two categories only — **ambient** (spatial guidance + mood) and **task** (focused work/reading).
- **Master controls:** Act on ambient only. Never activate task lights.
- **Dimming:** All ambient is dimmable. Task lights generally dimmable. Bathroom dimming NOT required.
- **Stealth / wildlife mode:** Red or blue ambient options to minimise exterior light spill. Task lights remain conventional white.

---

## 1. Interior Lighting

### 1.1 Zones

| Zone | Area | Ambient | Task | Dimming |
|---|---|---|---|---|
| Zone 1 | Entry + Bathroom | Yes | No special requirement | Ambient yes; bathroom not required |
| Zone 2 | Kitchen + Hall | Yes (hidden/indirect preferred) | Galley: sink + cooktop (separate switches) | Yes |
| Zone 3 | Sleeping + Sitting | Yes (ceiling + indirect) | Reading lights | Yes |
| Master | All zones | Ambient on across all zones | NOT activated | — |

### 1.2 Ambient Lighting Behaviours

- Hidden/indirect preferred (warm, non-glare).
- Provides spatial guidance for walking at night.
- **Every cabinet and drawer interior** lit when opened (door-triggered switch, controller, or sensor — method TBD).
- Under-bed and under-structure ambient hidden lighting around bed and sitting area.
- Under-cabinet / toe-kick indirect lighting in kitchen and walking areas.
- Optional decorative hook lights (Nixie-tube style) — nice-to-have; provide hardwired or USB power point rather than batteries.

### 1.3 Task Lighting

| Location | Requirement | Switch |
|---|---|---|
| Kitchen sink | Dedicated task light | Independent switch |
| Kitchen cooktop | Dedicated task light | Independent switch (NOT shared with sink) |
| Sitting area | Reading lights at seating corners (approx 4) | Independent from ambient master |
| Bed (night mode) | 2 reading lights at head/upper corners | Independent from ambient master |
| Bathroom | Adequate light only | No special task requirement |

### 1.4 Day / Night Mode Lighting Behaviour

| Mode | Bed position | Ambient source | Task available |
|---|---|---|---|
| Day | Raised | Under-bed ambient lights sitting area | Reading lights available |
| Night | Lowered | Ceiling ambient low-level | 2 bed reading lights |

### 1.5 Colour / Stealth / Wildlife Mode

- Ambient supports **white + red/blue** modes.
- Red/blue for wildlife/low-impact use (turtle beaches etc.), not security.
- Task lights remain white only.

---

## 2. Interior Switches & Controls

### 2.1 Master Ambient Switch Locations (3 required)

| Location | Notes |
|---|---|
| Cab pass-through entry | Adjacent to pass-through; exact side TBD |
| Main entry door (inside) | Accessible on entry |
| Bed area | Night accessibility |

**Behaviour:** Turns on ambient across all zones. Does NOT activate task lighting.

### 2.2 Local Controls

- Sink task light — independent switch
- Cooktop task light — independent switch
- Reading lights — independent
- Each fan — independent switch
- Centralized control capability acceptable (Bluetooth/app) but must not add complexity

---

## 3. Interior AC Outlets & Charging

### 3.1 General Rules

- All outlets **flush wall-mounted** (no pop-up countertop outlets)
- Standard: **120V / 15A**; kitchen circuit possibly **20A**
- One **220V** outlet for washer or specialty appliance (shore-only; decision pending)

### 3.2 Kitchen Outlets

| Circuit | Load |
|---|---|
| Duplex outlet (2 receptacles) | Instapot, blender/grinder |
| Dedicated circuit | Induction cooktop (2-burner) |
| Dedicated circuit | Convection microwave/oven |

### 3.3 Sitting Area Outlets

- One duplex outlet each side (left + right)
- Primary charge station: laptops, phones, tablets, TV/monitor accessories

### 3.4 Bathroom / Medicine Cabinet

- Medicine cabinet: 3–4 charging points
- Supports: toothbrushes × 2, shaver, misc
- Items kept continuously charged

### 3.5 Electronics Charging Zone

- Dedicated drawer(s) with outlets for:
  - Camera battery chargers
  - Drone batteries
  - GoPros
  - Misc rechargeable gear
- Location: near sitting/work zone (cabinetry placement TBD)

### 3.6 Vacuum Charging

- Dedicated outlet for vacuum (location TBD)

---

## 4. Exterior AC Outlets

| Location | Requirement |
|---|---|
| Outdoor kitchen box (passenger side) | Power inside box for appliance use (blender, induction outdoors) |
| Passenger side rear | Near rear storage hatch |
| Driver side rear | Near rear storage hatch / tool / grill proximity |

Minimum 3 exterior AC points. Exact count and placement TBD in layout.

---

## 5. Exterior Lighting

### 5.1 Storage / Garage Lighting

- All exterior storage boxes: light on when opened
- Garage: light on when garage door opened
- Utility ambient type

### 5.2 Awning Lighting

- Hardwired power provision (no battery management)
- Exact fixture TBD

### 5.3 Rock Lights (Undercarriage)

- **6 rock lights** total — front / mid / rear
- Manual control (no motion trigger)
- Blue colour mode nice-to-have for dark step-out situations

### 5.4 Security Flood Lighting

| Position | Requirement |
|---|---|
| Front | 4 × round lamps preferred (retro style) over single bar |
| Driver side mid | High-mount flood on habitat wall |
| Passenger side mid | High-mount flood on habitat wall |
| Rear | Flood covering rear perimeter |

Goal: single-shot full perimeter illumination on demand.

### 5.5 Infrared (IR) for Cameras

- IR illumination around full camper perimeter
- Separate from visible security floods
- Must be powered and wired to camera positions

---

## 6. Cab Electrical

- **One standard dome/task light** only
- No ambient lighting system in cab
- Flashlight/torch for map-reading tasks
- Rationale: reduce complexity; cab not used for night-driving operations

---

## 7. Appliance & Load Inventory

### 7.1 Off-Grid Loads (battery + inverter capable)

| Category | Item | Notes |
|---|---|---|
| Climate | Roof fan × 2 | Model TBD |
| Lighting | All interior ambient zones | Zoned + dimmable |
| Lighting | All interior task lights | Galley + reading |
| Lighting | Cabinet/drawer lights | Door-triggered |
| Refrigeration | Fridge + freezer | Model + draw TBD |
| Cooking | Induction cooktop 2-burner | Model TBD |
| Cooking | Convection microwave/oven | Model TBD |
| Cooking | Instapot | |
| Cooking | Blender / grinder | |
| Connectivity | Starlink | Roof-mounted; internal power + router |
| Connectivity | Router / Wi-Fi (Pepwave or similar) | |
| Entertainment | Smart TV / monitor | |
| Security | Cameras (perimeter) | |
| Security | NVR / recorder | Lightweight |
| Water | Internal pump | |
| Water | External stream intake pump | |
| Water | UV filtration system | Power draw TBD |
| Charging | Laptops, phones, tablets | |
| Charging | Camera / drone / GoPro batteries | |
| Charging | Toothbrushes × 2, shaver | |
| Charging | Heat pad | |
| Charging | Vacuum | |
| Medical | CPAP | If used |

### 7.2 Shore-Only Loads

| Item | Notes |
|---|---|
| Washer | Shore-only; reduces inverter/battery demand |

---

## 8. Shore Power & Global Compatibility

- Must accept **120V / 60Hz** (North America)
- Must accept **230V / 50Hz** (EU / India / international)
- Dual-input capability required
- Shore inlet location: either side acceptable (TBD)
- Integrates with inverter/charger architecture (TBD)

---

## 9. Roof Penetrations / Cable Routing

- Consolidated roof conduit/penetration for:
  - Solar cabling
  - Starlink cabling
- Route toward battery/electrical zone
- Minimise number of roof holes (prefer single consolidated entry point)

---

## 10. Constraints (DO NOT violate)

- No pop-up countertop outlets
- No cab ambient lighting system
- Sink and cooktop task lights MUST be on separate switches
- Task lights MUST NOT activate via master ambient switches
- Avoid switch-gating appliances — use proper fusing/breakers

---

## Related Files

- [PLAN-electrical-layout.md](PLAN-electrical-layout.md) — battery + inverter placement decisions
- [DECISIONS-ELEC-001-open-decisions.md](DECISIONS-ELEC-001-open-decisions.md) — open decisions and todos
- [DEC-004-electrical-placement.md](../DEC-004-electrical-placement.md) — component placement decision

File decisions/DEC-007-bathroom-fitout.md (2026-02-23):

# Decision: Bathroom Fitout

**ID:** DEC-007
**Date:** 2026-02-21
**Status:** FINAL

---

## Decisions

| Item | Decision |
|---|---|
| Sink | **No bathroom sink** |
| Medicine cabinet | **Yes — included** |
| Towel warmer | **Yes — included** |

## No Sink

- Eliminates a dedicated plumbing branch (supply + drain) in the bathroom zone, reducing complexity, weight, and potential leak points.
- Handwashing done at the kitchen sink, which is already plumbed.
- Saves space in a compact wet-room.

**Implications:**
- No cold/hot supply lines to bathroom required.
- No bathroom drain or trap required.
- Wet-room wall finish does not need to accommodate a sink cutout.

## Medicine Cabinet

- Wall-mounted above the toilet or on the door-adjacent wall.
- Surface-mount preferred (avoids cutting into GRP sandwich panel).
- Must be secured per [DEC-005](DEC-005-grp-shell-attachment-method.md) attachment method (threaded inserts or backing plate).

## Towel Warmer

- Electric (not hydronic) — avoids adding a heating circuit branch to the bathroom plumbing.
- 12V DC or 230V AC depending on final electrical plan — confirm with [electrical layout](electrical/PLAN-electrical-layout.md).
- Wall-mounted; attachment per DEC-005.

## Scope

Applies to the bathroom/wet-room area only. Kitchen unaffected.

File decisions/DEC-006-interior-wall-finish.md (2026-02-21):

# Decision: Interior Wall Finish Strategy

**ID:** DEC-006
**Date:** 2026-02-21
**Status:** FINAL

---

## Context

The habitat uses GRP composite sandwich panels whose inner surface is GRP + gelcoat. The finish strategy must:

- Minimise condensation risk and cold corners
- Resist mildew/mold
- Have low water absorption
- Be wipe-clean
- Be repairable over long-term expedition vibration

## Decision

1. **Primary wall/ceiling finish:** Paint directly on the interior GRP/gelcoat. No additional wall liner panels or full-wall wallpaper.
2. **Kitchen backsplash zone only:** Use fiberglass wallpaper (glass-fiber wall covering) in the backsplash area, then paint over it (or use as finished surface per product spec).

## Rationale

- Painted GRP is non-organic, low absorption, and easy to clean. Avoids creating hidden cavities where moisture can be trapped.
- Keeping the finish simple reduces the chance of mildew/mold growth behind coverings.
- Fiberglass wallpaper in the backsplash provides extra impact/scratch resistance and a replaceable reinforcement layer in the highest splash/abuse zone, while keeping the rest of the cabin moisture-safe.

## Build Notes

- Painting GRP requires proper prep: **clean/de-wax → sand for tooth → epoxy primer (if needed) → durable topcoat**
- Use **satin/eggshell** sheen where possible — better defect hiding while remaining wipeable
- Backsplash wallpaper adhesive/primer must be compatible with GRP and the chosen paint system

## Scope

All interior wall/ceiling surfaces in the habitat, **except** the kitchen backsplash area.

## Related Decisions

- [DEC-005](DEC-005-grp-shell-attachment-method.md) — GRP shell attachment method (same panel system)

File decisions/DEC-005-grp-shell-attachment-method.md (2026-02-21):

# Decision: GRP Shell Cabinet & Furniture Attachment Method

**ID:** DEC-005
**Date:** 2026-02-21
**Status:** FINAL

## Decision Maker

- **Human:** Mithril (owner/builder)
- **AI Assistant:** Claude (structural guidance)

## Context

The Gimli2 habitat is built on a GRP (Glass Reinforced Plastic) shell. We need a reliable, non-invasive method to attach:
- Kitchen cabinets (upper and lower)
- Pantry
- U-shaped sofa/dinette seating

The shell must not be drilled through or punctured, as this would compromise the structural integrity and weatherproofing of the GRP monocoque. The attachment method must handle:
- Road vibration
- Lateral sway in transit
- Impact loads (people dropping into seating)
- Emergency braking forces

## Options Considered

### Option 1: Direct drilling into GRP shell

**Description:** Drill and bolt furniture directly into the GRP shell walls.

**Pros:**
- Simple, familiar construction method

**Cons:**
- Punctures shell weatherproofing
- Stress concentrations around holes in GRP
- Hard to relocate if layout changes
- Risk of delamination over time with vibration

### Option 2: Timber battens bonded to shell

**Description:** Epoxy timber battens to the interior GRP walls; screw furniture into battens.

**Pros:**
- No shell punctures
- Familiar to carpenters

**Cons:**
- Timber absorbs moisture, swells, and degrades
- Glue bond to GRP can fail if timber moves seasonally
- Lower long-term durability

### Option 3: Fiberglass rails bonded to GRP shell (SELECTED)

**Description:** Bond fiberglass flat bar or angle sections to the interior GRP walls using marine-grade adhesive sealant (e.g., Sikaflex 552 or 3M 5200). All furniture and cabinets screw into the rails, not the shell.

**Pros:**
- No shell punctures — weatherproofing fully preserved
- Fiberglass-to-fiberglass bond is chemically compatible and extremely strong
- Marine adhesives work in shear; slight glue gap (1–2 mm) absorbs road vibration
- Fiberglass holds screws very well; pre-drilling prevents cracking
- Rails can run long and continuous (more load distribution)
- L-shaped profile option adds resistance to pull-off, twist, and shear
- Proven in marine and vehicle construction
- No creep, fatigue, or moisture issues

**Cons:**
- Requires careful surface prep before bonding
- Cure time before loading (24–72 hrs depending on adhesive)
- More upfront planning to position rails correctly

## Decision

**Fiberglass rails bonded to the GRP shell** using marine-grade structural adhesive. All cabinets, pantry, and sofa framing attach via screws into these rails. The GRP shell is never drilled through.

## Rail Specifications

### Thickness
| Location | Rail Thickness | Rationale |
|---|---|---|
| Upper cabinets | ½" (12–13 mm) | Sufficient stiffness for overhead loads |
| Lower kitchen cabinets | ½"–⅝" (12–16 mm) | Base and counter-height rails |
| U-shaped sofa / seating | **⅝" (15–16 mm)** | Human impact and dynamic seating loads |

### Profile Shape
- **Flat rectangular strip** (½"+ × 2"–3" tall): simplest, easiest to align, suits most cabinet runs
- **L-shaped angle** (½"+ × 2"×2" legs): preferred behind upper cabinets, sofa backs, and pantry walls — resists pull-off, twist, and shear

### Rail Spacing
- Maximum 18–24" between horizontal rails
- For seating: closer spacing preferred ("ladder rungs on the wall")
- U-sofa corners: short vertical rails to create a rigid box frame

### Sofa Rail Layout (minimum)
1. Rail at seat height
2. Rail near floor
3. Short vertical rails at each corner

## Fastener Specification

- **Type:** Stainless steel or coated wood screws
- **Length:** 1"–1¼" into the rail
- **Practice:** Pre-drill all holes in fiberglass to prevent cracking

## Adhesive Specification

- **Product:** Sikaflex 552 or 3M 5200 (or equivalent marine structural adhesive sealant)
- **Glue gap target:** 1–2 mm (not razor-thin; allows shear flex and vibration damping)
- **Surface prep:** Both GRP shell and fiberglass rail must be clean, dry, and lightly abraded before bonding

## Visual Summary

```
[ Cabinet / Furniture ]
         │
    screws into
         │
[ Fiberglass Rail ]   ← ½"–⅝" thick flat or L-profile
         │
   bonded with
   Sikaflex 552
         │
[ GRP Shell Wall ]
```

No holes. No punctures. No shell compromise.

## Rationale

The fiberglass rail method is the standard approach in marine construction for exactly this loading scenario: dynamic loads, vibration, moisture, and structures that must not be punctured. Using fiberglass rail bonded to a fiberglass shell is chemically and mechanically ideal — same material family, compatible thermal expansion, and no moisture ingress risk. The marine adhesives specified are designed for this exact use case and will outlast the vehicle.

## Implications

- All furniture design must account for rail positions (rail locations determine screw points)
- Rail positions should be planned before any CAD furniture modeling is finalized
- Surface prep protocol must be documented before build phase begins
- No furniture may be screwed directly into the GRP shell under any circumstances

## Requirements Addressed

- Structural integrity of GRP monocoque preserved
- Furniture and seating safe for transit dynamic loads
- Long-term durability in variable climate/moisture environment

## Related Decisions

- DEC-003: Alde Heating Placement — shares the rear garage shell interior
- DEC-004: Electrical Placement — electrical conduit routing must coordinate with rail positions

## Notes

- ⅝" rails are recommended for any surface where people sit or lean dynamically
- Continuous long rails are stronger than short stub rails — maximize rail length where possible
- L-profile rails preferred wherever pull-off force is a concern (upper cabinets, sofa backs)
- Future phase: produce a cut list of rail lengths per zone once furniture layout is finalized in CAD

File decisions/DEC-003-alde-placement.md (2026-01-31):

## Decision: Alde Heating System Placement

**ID:** DEC-003
**Date:** 2026-01-31
**Status:** PROPOSED

## Context
The user has decided to prioritize Axle-Centered placement for Water and Batteries.
- **Batteries:** Driver Side Mid-Ship (Under Dinette).
- **Water:** Split Mid-Ship (Kitchen & Dinette).
- **Alde Constraint:** "Alde is not the heavy one... We can run it under the chassis."

## Options Considered

### Option 1: Rear Garage / U-Bench (RECOMMENDED)
**Description:** Place Alde in the **Rear Garage Shell (Driver Side Arm)** at ~X=500.
**Pros:**
- **Space:** The Batteries/Water have moved FORWARD to the axle (X=2380), leaving the Garage Shell (X=0..600) **EMPTY** and available!
- **Distribution:** Consolidates mechanicals in the rear.
- **Heating:** Ideally located to heat Bed and Dinette.
**Cons:**
- **Chassis Routing:** Requires coolant lines from engine to rear.

### Option 2: Front Bathroom Vanity
**Description:** Original proposal.
**Status:** Valid but less optimal for heating distribution.

## Decision
**Select Option 1:** Place the Alde unit in the **Rear Garage Shell (Driver Side)**.

## Rationale
Since the heavy Batteries and Water Tanks have moved mid-ship to the axle (X=2380), the Garage Shell volume (X=0 to 600) is now **vacant**. This is the perfect spot for the lightweight Alde heater. It reclaims the rear volume for useful systems without affecting the specific gravity balance significantly (only 15kg).

## Status
PROPOSED - Awaiting final confirmation.

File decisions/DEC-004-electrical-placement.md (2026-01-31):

## Decision: Electrical System Placement

**ID:** DEC-004
**Date:** 2026-01-31
**Status:** PROPOSED

## Decision Maker
- **Human:** User
- **AI Assistant:** Antigravity

## Context
The electrical system is substantial:
- **Inverter:** Victron MultiPlus-II 3000VA (Large vertical footprint, high heat).
- **Solar:** Global offshore capabilities (MPPTs).
- **Distribution:** Fuses, Busbars (Lynx system).
- **Batteries:** Located mid-ship driver side (resolved in CONFLICT-001).

Space Constraints:
- Inverter (580mm H) does not fit under Dinette Benches (450mm H).
- Driver Rear Garage Arm is occupied by Alde Heater (DEC-003).

## Options Considered

### Option 1: Passenger Rear Garage Arm (RECOMMENDED)
**Description:** Dedicate the Passenger Side Rear U-shell arm to electrical components.
**Pros:**
- **Volume:** 600x600x860mm space is sufficient for vertical mounting of Inverter + Solar Controllers.
- **Separation:** Keeps high-voltage/high-heat electronics away from water/plumbing (Kitchen/Bath).
- **Ventilation:** Can be vented to rear/side easily.
- **Balance:** Balances the Alde heater mass on the Driver side.
**Cons:**
- **Cable Run:** Requires crossing the aisle (~2m) to reach batteries. Acceptable.

### Option 2: Tall Cabinet (Driver Side)
**Description:** Upper section of a floor-to-ceiling cabinet.
**Pros:**
- **Access:** Eye-level controls.
**Cons:**
- **Center of Gravity:** High mass (20kg+) mounted high up is bad for vehicle dynamics.
- **Storage:** Consumes prime clothing/pantry space.

## Decision
**Select Option 1:** Place the Electrical Core (Inverter, MPPT, Dist) in the **Passenger Rear Garage Arm**.

## Rationale
This creates a symmetrical "Mechanical Rear":
1.  **Driver Rear:** Heating (Alde).
2.  **Passenger Rear:** Electrical (Victron).
3.  **Mid-Ship Passenger:** Batteries are just forward in the Kitchen Base. Cable run is short (~1.5m) and stays on the same side of the vehicle!

## Status
APPROVED - Confirmed by Mass Balance analysis.

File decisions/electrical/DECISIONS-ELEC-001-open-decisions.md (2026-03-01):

# Electrical Open Decisions & Todos

**ID:** DECISIONS-ELEC-001
**Version:** 0.1
**Date:** 2026-02-23
**Status:** ACTIVE

These todos must be resolved before load calculations and system sizing can be finalised.
Work through Section A (appliance selection) first — those answers feed directly into Section B (engineering).

---

## A — Appliance / Model Selection (resolve first)

These drive the load table and therefore all sizing calculations.

- [ ] **A1** Select induction cooktop model (2-burner) — need rated wattage + surge
- [ ] **A2** Select convection microwave/oven model — need rated wattage + surge
- [ ] **A3** Confirm roof fan model (MaxxFan or alternative) — need current draw × 2
- [ ] **A4** Select washer model — confirm 120V or 230V; shore-only; drum size
- [ ] **A5** Confirm fridge model — need continuous watt-hours/day
- [ ] **A6** Confirm freezer model (separate unit or combined?) — need continuous watt-hours/day
- [ ] **A7** Confirm Starlink dish model (Standard / HP / Mini) — need idle + active draw
- [ ] **A8** Confirm router/Pepwave model — need idle draw
- [ ] **A9** Confirm CPAP model if used — need wattage + nightly hours
- [ ] **A10** Confirm UV filter system model — need wattage + duty cycle

---

## B — Electrical Engineering & Sizing (requires A complete)

- [ ] **B1** Build full load table (continuous + peak/surge) for all items in REQ-ELEC-001 §7
- [ ] **B2** Calculate daily amp-hour demand (watt-hours/day → Ah at 12V or 48V bus)
- [x] **B3** Size battery bank — **DECIDED 2026-02-28:** 4 × Victron NG 300 Ah (LFP) = 1 200 Ah total at 24 V (28.8 kWh nominal). Autonomy days TBC once load table (B1/B2) is complete.
- [ ] **B4** Size inverter — must cover simultaneous peak loads (induction + microwave + other)
- [ ] **B5** Size shore power charger — for both 120V/60Hz and 230V/50Hz input
- [ ] **B6** Size solar array — panels + MPPT controller for daily recharge target
- [ ] **B7** Define AC distribution: branch circuits, breaker sizing, GFCI/AFCI zones
- [ ] **B8** Define DC distribution: lighting zones, fans, pumps, security, networking
- [x] **B9** Define battery bus voltage — **DECIDED 2026-02-28:** 24 V bus (driven by Victron NG 300 Ah battery selection, 4S config)
- [ ] **B10** Determine alternator charging strategy — truck alternator → DC-DC charger sizing

---

## C — Switching & Control Architecture

- [ ] **C1** Select ambient lighting controller — must support: zoning, dimming, white + red/blue colour, 3× master switch locations
- [ ] **C2** Define cabinet/drawer lighting trigger method — door-switch vs controller vs sensor
- [ ] **C3** Define master ambient switch wiring — 3-way logic or smart switch bus
- [ ] **C4** Decide Bluetooth/app control integration — confirm platform (e.g., KNX, Victron Cerbo, custom ESP32, commercial smart switch)
- [ ] **C5** Define bed day/night mode lighting changeover — automatic (bed position sensor) or manual switch?

---

## D — Placement & Layout

- [ ] **D1** Finalise kitchen duplex outlet exact position on wall
- [ ] **D2** Finalise sitting area outlet positions relative to windows and cabinetry
- [ ] **D3** Finalise medicine cabinet internal layout — 3 or 4 charging points; USB-A/C mix
- [ ] **D4** Decide vacuum charging outlet location
- [ ] **D5** Decide electronics drawer location (near sitting/work zone) and ventilation strategy for charging heat
- [ ] **D6** Finalise exterior outlet positions — outdoor kitchen box, passenger rear, driver rear
- [ ] **D7** Finalise shore power inlet side (driver or passenger) and connector type (30A TT-30 / 50A 14-50 / CEE17 combo)
- [ ] **D8** Finalise roof penetration location and conduit routing path to battery zone

---

## E — Exterior Lighting Implementation

- [ ] **E1** Confirm rock light model and mounting positions (6 total: front / mid / rear each side)
- [ ] **E2** Confirm rock light blue mode — included in selected model or separate fixture
- [ ] **E3** Select front security flood type — confirm 4 × round lamps vs bar; mounting positions
- [ ] **E4** Confirm side flood mounting height and bracket approach on habitat GRP walls
- [ ] **E5** Confirm rear flood mounting point (rear wall, bumper bar, or box lid)
- [ ] **E6** Select IR emitter model and confirm placement covers camera FOV at all positions
- [ ] **E7** Confirm awning light model and hardwire connection point

---

## F — Global / Shore Power

- [ ] **F1** Confirm dual-voltage strategy — single dual-input inverter/charger vs separate units
- [ ] **F2** Confirm 220V washer outlet — dedicated circuit, shore-only interlock method
- [ ] **F3** Confirm one 220V general outlet location (if included beyond washer)

---

## Sequencing Guide

```
A (appliances) → B1 load table → B2-B6 sizing → B7-B10 distribution design
                                               → C (controls)
                                               → D (placement)
A + D → E (exterior lighting layout)
B5 + F → shore power architecture
```

Start with **A1–A6** (cooking + refrigeration) as these dominate the load table.

---

## Related Files

- [REQ-ELEC-001-electrical-requirements.md](REQ-ELEC-001-electrical-requirements.md) — full requirements
- [PLAN-electrical-layout.md](PLAN-electrical-layout.md) — battery + inverter placement

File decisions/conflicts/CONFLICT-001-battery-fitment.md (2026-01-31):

## Conflict Detected: Battery Modules vs Garage Shell Depth

**Type:** Constraint Conflict (Physical Fitment)

**Artifact A:** `habitat.yml` (Battery Specs from User Prompt)
- Module Dimensions: 540 mm (L) x 250 mm (W) x 220 mm (H)
- Required Clearance: 25 mm all sides
- Minimum bounding box per module: **590 mm x 300 mm**

**Artifact B:** `zones/functional/ZONE-003-garage-shell.yml`
- Current Shell Depth: **509 mm**
- Internal Arm Width: 473 mm

**Nature of Conflict:**
The battery modules (540mm long) physically cannot fit inside the Garage Shell arms (509mm deep), regardless of orientation. They protrude by at least 31mm before adding clearance or wall thickness.

**Detected During:** `scripts/battery_layout_solver.py` execution.

**Suggested Resolution Options:**
1.  **Increase Garage Shell Depth**: Extend `shell_depth` from 509mm to **600mm**.
    *   *Pros*: comfortably fits batteries (590mm required with clearance).
    *   *Cons*: Reduces Living/Dinette floor space by ~9cm; slightly encroaches on Kitchen aisle.
    *   *Status*: **RECOMMENDED**

2.  **Relocate Batteries**: Move batteries to a different zone (e.g., under false floor or in a new cabinet).
    *   *Pros*: Preserves garage shell geometry.
    *   *Cons*: Raises center of mass (bad for vehicle dynamics); consumes prime living storage.

3.  **Change Battery Spec**: Switch to smaller/denser modules.
    *   *Pros*: Fits current geometry.
    *   *Cons*: User specified "6 identical modules" as a hard constraint.

**Agent Recommendation:**
Option 1. Increasing the shell depth to 600mm aligns with standard countertop/cabinet depths (often 600mm) and provides necessary volume for both batteries and larger water tanks.

**Status:** RESOLVED
**Resolution:** Adopted Scenario E (Mass Balance).
- **Placement:** Batteries moved to **Passenger-Side Kitchen Base**.
- **Rationale:** Necessary to counter-balance the 500L (450kg) Driver-side diesel tank.
- **Fit:** Fits in 600mm deep cabinetry alongside Water Tank 1.

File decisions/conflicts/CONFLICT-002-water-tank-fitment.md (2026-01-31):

## Conflict Detected: Water Tank Fitment vs Axle Loading

**Type:** Constraint Conflict (Physical Fitment & Weight Distribution)

**Artifact A:** `habitat.yml` (Water Tank Specs from User Prompt)
- Option A: Single 1200x600x700mm (500kg).
- Option B: Split 2x 900x500x560mm (250kg each).
- **CRITICAL CONSTRAINT:** Centroid must be near Rear Axle (X=2380mm).

**Artifact B:** `zones/functional/ZONE-003-garage-shell.yml`
- Current Shell Depth: 509mm.
- Location: "Rear section" (X=0 to X=~1000mm).

**Nature of Conflict:**
1.  **Option A (Single Tank)**: Physically fits in the center channel width-wise, but forces the mass to the extreme rear (Centroid X ~600mm). This violates the axle loading constraint (Target X=2380mm) by nearly 1.8 meters, creating a dangerous "pendulum effect."
2.  **Option B (Split Tanks)**: Provides excellent weight distribution potential (can be placed mid-ship). However, the individual tanks (500mm wide) **do not fit** inside the current 509mm deep side shells (473mm internal width).

**Detected During:** `scripts/water_tank_solver.py` execution.

**Suggested Resolution Options:**
1.  **Adopt Option B + Increase Shell Depth to 600mm**:
    *   Enable Split Tanks (Option B).
    *   Increase `shell_depth` to **600mm** (matches CONFLICT-001 recommendation).
    *   Place tanks longitudinally starting from the garage shell and extending forward into the dinette/kitchen base units to hit X=2380 centroid.
    *   *Status*: **STRONGLY RECOMMENDED**

2.  **Custom Tank Shapes**:
    *   Commission custom L-shaped or narrower tanks to fit current geometry.
    *   *Cons*: High cost, long lead time.

**Agent Recommendation:**
This conflict double-confirms the need to standardize on a **600mm shell depth**. It solves both the battery fitment (CONFLICT-001) and enables the only viable water tank option (Option B) that respects vehicle dynamics.

**Status:** RESOLVED
**Resolution:** Adopted Scenario E (Mass Balance).
- **Water Tank 1 (Passenger):** Standard 560mm High tank in Kitchen Base (alongside Batteries).
- **Water Tank 2 (Driver):** **Custom Low-Profile Tank** (H=400mm) under Dinette Bench.
- **Rationale:** Splits water mass 250kg/250kg. The Passenger tank helps counter the Diesel mass.

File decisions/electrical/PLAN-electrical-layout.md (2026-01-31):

# Decision Log: Battery & Electrical Component Placement

## Core Question
Now that the Water Tank is defined (Low Profile U-Shape), where should the **Battery Bank (300kg)** and **Electrical Core (Inverter/Fuses)** be placed?
Also, how should we utilize the newly available space in the Rear Bench (above the low-profile tank connector)?

## Analysis: Component Proximity

### 1. Battery <-> Inverter
**Rule:** These should be as close as physically possible.
*   **Reason:** High current (up to 250A-300A for a 3kW inverter).
*   **Impact:** Long cables require massive gauge (4/0 AWG), are heavy, expensive, and suffer voltage drop.
*   **Target:** < 1 meter cable run.

### 2. Battery <-> Center of Gravity (Axle)
**Rule:** Heavy items (300kg) must balance the vehicle.
*   **Current State:**
    *   Water Tank (500kg) is rear-biased (Centroid Z ~ -700).
    *   Axle is at Z = -250.
    *   Rear Garage structure is heavy and far back.
*   **Impact:** Placing batteries in the rear (Z ~ -1700) would make the vehicle dangerously tail-heavy.
*   **Recommendation:** Batteries **MUST BE FORWARD** of the axle to counterbalance the rear water/structure.

## Evaluation of Locations

### Option A: Rear Bench (Inside U-Shell)
*   **Mass Balance:** **POOR CRITICAL**. Adds 300kg to the rear lever arm.
*   **Electrical Efficiency:** Good if inverter is also there.
*   **Conclusion:** Rejected due to weight distribution risks.

### Option B: Forward Kitchen Base (Passenger Side)
*   **Mass Balance:** **EXCELLENT**. Placing 300kg at Z ~ +800 acts as a counterweight to the rear loads.
*   **Electrical Efficiency:** Good location for centralized distribution.
*   **Space:** The "Toe-Kick" water tank extension is only 200mm high. The kitchen base is ~860mm high.
    *   Tank: 0-200mm.
    *   **Available for Voltage:** 200mm - 800mm.
    *   Plenty of space above the water tank extension.

## Proposed Layout

### 1. Electrical & Battery Zone (Passenger Kitchen/Dinette Base)
*   **Location:** Passenger side, forward of the U-Shell arms.
*   **Stack:**
    *   **Level 0 (Floor):** Water Tank Extension (Height 200mm).
    *   **Level 1 (Shelf above Tank):** **Battery Bank** (300kg). Securely mounted to chassis/floor through the shelf.
        *   Proximity to Axle: Forward (~1m in front of axle).
    *   **Level 2 (Vertical Compartment):** **Inverter/Charger + Fuses + Busbars**.
        *   Mounted directly above or adjacent to batteries.
        *   Cable run: Extremely short (~30-50cm).

### 2. Rear Bench Space (Utility Zone)
*   **Space Available:** Above the slim 150mm deep water manifold.
*   **Usage:**
    *   **Plumbing Core:** Water Pump, Accumulator, Water Filter, Valves.
        *   *Reason:* Close to the main tank connector. Leaks are contained in the "wet" rear zone.
    *   **Storage:** Light items only (Bedding, Clothes).

## Decision Recommendation
1.  **Keep Batteries Forward:** Essential for safe vehicle handling.
2.  **Keep Inverter with Batteries:** Essential for electrical performance.
3.  **Use Rear Bench for PLUMBING:** Keep the water pump and complex manifold logic back there, close to the tank source.

**Status:** Proposed for User Approval.

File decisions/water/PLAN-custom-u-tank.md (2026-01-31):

# Decision Log: Custom U-Shaped Water Tank Feasibility

## Context
The user requested an analysis of a custom U-shaped water tank integrated into the U-shaped rear seating/garage shell structure.
The goal is to maximize water capacity (target 500-600L), improve mass balance (centering weight), and utilize the "dead space" under the seating.

## Constraints & Assumptions
1.  **Geometry:**
    *   **Rear Section:** 2280mm (W) x 600mm (D) x 400mm (H)
    *   **Side Arms:** Two arms, extending forward from the rear section.
    *   **Arm Dimensions:** 600mm (W) x 800mm (L) x 400mm (H) (Length reduced to 800mm to fit Living Zone).
    *   **No Wheel Wells:** Confirmed by user. The floor is flat.

2.  **Mass Balance:**
    *   **Rear Axle Position:** ~2140mm from interior rear wall (from `habitat.yml` line 43 derived position, to be verified).
    *   **Diesel Tank:** Z = -500 (approx mid-rear).
    *   **Centroid Goal:** The tank's center of mass should be as close to the axle as possible.
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

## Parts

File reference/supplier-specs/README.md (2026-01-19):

# Supplier Specifications

This folder contains product specifications, datasheets, and documentation from suppliers.

## Purpose

- Store authoritative product dimensions and specifications
- Reference source for design constraints
- Maintain traceability to supplier documentation

## File Organization

```
supplier-specs/
├── README.md                    # This file
├── habitat/                     # Habitat shell specs (Osterath)
│   └── *.pdf
├── windows/                     # Window specifications
│   └── *.pdf
├── doors/                       # Door specifications
│   └── *.pdf
├── hvac/                        # HVAC components
│   └── *.pdf
├── electrical/                  # Electrical components
│   └── *.pdf
├── plumbing/                    # Plumbing fixtures
│   └── *.pdf
└── furniture/                   # Built-in furniture specs
    └── *.pdf
```

## Naming Convention

`[supplier]-[product]-[version].[ext]`

Example: `osterath-habitat-1225AF-specs.pdf`

## Usage

1. Add supplier PDFs to the appropriate subfolder
2. Reference in habitat.yml or requirements files
3. Extract key dimensions into YAML for programmatic use

## Notes

- These files are reference-only
- Do not modify supplier documents
- If specs change, archive old version and add new

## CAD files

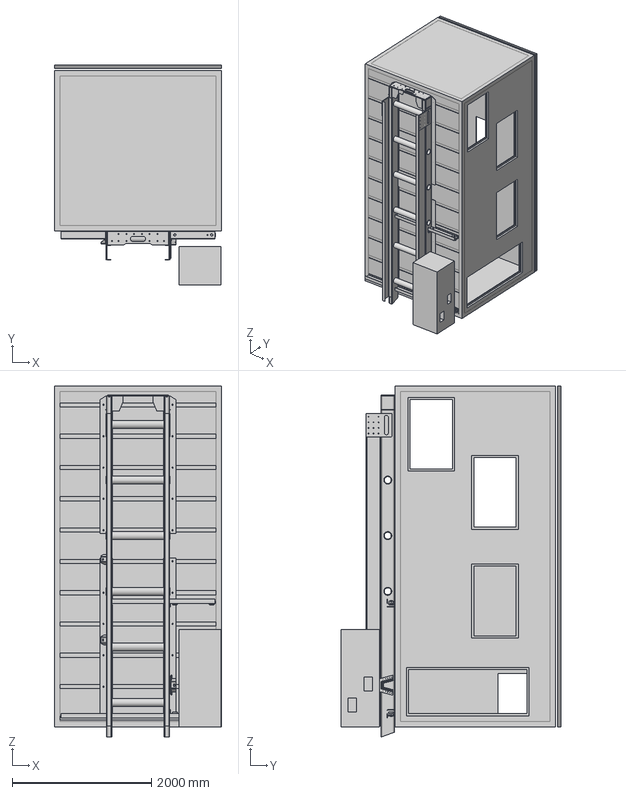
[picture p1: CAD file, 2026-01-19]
reference/Osterath_Habitat_1225 AF.step
2404.0 x 3158.0 x 5047.0 mm
Wohnkabine Rishi
801366_Rahmenböckchen x 2
801934_Längsträger x 2
801936_Befestigungsplatte x 2
801937_Befestigungsplatte x 2
801938_Flanschplatte x 2
801939A_Flanschplatte
801742_Stegblech x 2
2512178_Dummy_Chassisende x 2
801776_Platte Seitenführung
801777_Winkel Seitenführung
801780_Kunststoffplatte Seitenführung x 2
802005_Kunststoffplatte Seitenführung
801778_Winkel Seitenführung
801781_Kunststoffplatte Längsführung x 2
801992_Verstärkungsblech x 2
801867_Doppel T-Träger x 2
801994_Stegblech x 2
801999_Lagerbolzen x 4
801865_Rillenkugellager W6205 2RS1 x 4
801866_Kunststoffrolle x 4
802000_Deckblech x 4
801635_Rundrohr_1 x 3
801635_Rundrohr x 3
801998_Verstärkungswinkel x 2
801867_Doppel T-Träger_1
2512178R_Kunststoffeinheit Beifahrerseite

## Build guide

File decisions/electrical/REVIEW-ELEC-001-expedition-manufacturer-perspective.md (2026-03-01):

# Expedition Manufacturer Review — Electrical System Design

**ID:** REVIEW-ELEC-001
**Date:** 2026-02-28
**Reviewing:** DESIGN-ELEC-001 v0.1
**Perspective:** As if reviewed by engineering teams at Unicat, Bliss Mobil, or EarthRoamer
**Status:** REVIEW — For owner consideration

---

## Executive Summary

The Gimli2 electrical design is a solid first draft with well-reasoned component selection and honest load analysis. The Victron ecosystem choice, 24V bus, and 2050W solar array are consistent with current expedition vehicle best practices. However, the design has gaps that a production expedition builder would address before signing off — primarily around **redundancy, wiring standards, thermal management, and generator backup**. None are dealbreakers; all are solvable.

**Overall rating: 7/10 for a first draft** — with the items below addressed, this moves to production-ready.

---

## 1. How Gimli2 Compares to Industry Benchmarks

| Parameter | Gimli2 | Unicat MD56c | Bliss Mobil 15ft | EarthRoamer LTx | Assessment |
|---|---|---|---|---|---|
| Battery capacity | 30.7 kWh | 24.6 kWh | 10–20 kWh | 18 kWh | **ABOVE AVERAGE** — generous bank |
| Solar array | 2,050 W | 1,850 W | 860–1,000 W | 1,480 W | **ABOVE AVERAGE** — excellent for the roof size |
| Inverter | 4,000 W cont. | Dual inverters | Victron | 9,000 W (LTx) | **ADEQUATE** — see note on redundancy |
| Bus voltage | 24 V | 24 V | 24 V | 24 V | **MATCHES INDUSTRY STANDARD** |
| Autonomy (no solar) | 6.6 days (conservation) | ~14 days (claimed) | ~7 days | ~5–7 days | **COMPETITIVE** — but see note |
| Generator | None | Yes (diesel) | Optional | Auto-start engine | **GAP — see Finding #1** |
| Total electrical weight | 407 kg | N/A | N/A | N/A | Reasonable for the capacity |

---

## 2. Critical Findings

### FINDING #1 — No Generator or Engine Auto-Start (CRITICAL GAP)

**The issue:** Every major expedition builder includes either a dedicated diesel generator (Unicat, Bliss Mobil) or an auto-start engine charging system (EarthRoamer). The Gimli2 design relies entirely on solar + alternator DC-DC + shore power. In a 10-day zero-solar scenario (jungle canopy, sustained overcast, mechanical breakdown preventing driving), the system runs dry at ~6.6 days.

**Why this matters for world travel:** In equatorial rainforest, dense jungle, or northern European winter, you may face extended periods with near-zero solar and no access to shore power. The alternator charges at 800W — but only when driving. If the truck is parked for repairs, you have no backup charge source.

**Mitigations (choose one or combine):**

| Option | Weight | Cost | Complexity | Recommendation |
|---|---|---|---|---|
| **A. Portable diesel generator** (e.g., Honda EU2200i or Dometic T4500) | 21–45 kg | $1,000–4,000 | Low — external, fuel from main tank | RECOMMENDED for world travel |
| **B. Engine auto-start system** (EarthRoamer approach) | ~5 kg (relay + controller) | $500 | Medium — auto-starts truck engine when SOC drops below threshold, charges via DC-DC | Elegant but adds engine hours |
| **C. 5th battery** (+7.7 kWh, extends to ~8.4 days) | 52 kg | ~$3,500 | None | Buys time but doesn't solve the root problem |
| **D. Accept the limitation** | 0 | $0 | None | Viable if travel plans avoid extended zero-solar scenarios |

**Production builders' choice:** Unicat and Bliss Mobil spec a dedicated generator. EarthRoamer uses auto-start. For a world-travel rig, Option A (portable generator, fuel from main diesel tank) is the most pragmatic.

---

### FINDING #2 — Single Inverter, Single Point of Failure (HIGH)

**The issue:** The design uses a single MultiPlus-II 24/5000. If it fails in a remote location, you lose all AC power — no cooking (induction), no microwave, no charging from shore power. Unicat specs dual inverters; Bliss Mobil uses redundant Victron units.

**Why this matters:** Inverters are the highest-stress component in the system (thermal cycling, surge loads, vibration). They fail. In a Namibian desert or Mongolian steppe, replacement lead time could be weeks.

**Mitigations:**

| Option | Weight | Cost | Notes |
|---|---|---|---|
| **A. Carry a spare MultiPlus-II** | 29 kg | ~$2,500 | Simplest. Pre-wired connector for fast swap. Victron units are field-replaceable. |
| **B. Dual MultiPlus-II in parallel** | +29 kg | +$2,500 | Active redundancy — both share load. If one fails, the other covers ~2,000W. Victron supports parallel operation natively. |
| **C. Add a small backup inverter** (e.g., Phoenix 24/1200) | 5 kg | ~$500 | Covers essential loads only (laptop, phone charging, lighting). Doesn't handle cooking. |
| **D. Accept and carry a spare** | 29 kg stored | $2,500 | Most weight-efficient — spare doesn't add parasitic losses. |

**Recommendation:** Option A (carry a pre-wired spare) for weight efficiency, or Option B (dual parallel) if the weight budget allows. A production Unicat would do Option B without question.

---

### FINDING #3 — No Wiring Standards Specification (MEDIUM-HIGH)

**The issue:** The design specifies wire gauges and fuse sizes but does not specify wiring construction standards. Production expedition vehicles use marine-grade practices because the environment (vibration, moisture, temperature cycling) is identical to offshore marine.

**What's missing:**

1. **Wire type specification** — All wiring should be tinned copper, marine-grade stranded (not solid), with cross-linked polyethylene (XLPE) or TXL insulation rated to 105°C minimum. Standard automotive PVC wire degrades in 3–5 years of expedition vibration.

2. **Termination standard** — All ring terminals should be adhesive-lined heat-shrink crimp terminals (not bare crimps). No twist-and-tape connections anywhere. Butt splices only with adhesive heat-shrink. This is non-negotiable for a rig expected to survive African corrugated roads.

3. **Connector standard** — All multi-pin connectors should be Deutsch DT/DTP series (IP67, vibration-rated) or equivalent. No Molex, no spade terminals in any location subject to vibration.

4. **Loom construction** — All wiring looms secured with Adel clamps (cushioned P-clips) at maximum 300mm intervals. No cable ties as primary restraint (they fatigue and snap). Looms protected with split corrugated conduit or woven loom tape.

5. **Labelling** — Every wire labelled at both ends with permanent heat-shrink labels. Brady or equivalent. Critical for field troubleshooting in a remote workshop.

**Mitigation:** Add a "Wiring Construction Standards" section to the design document specifying ABYC E-11 (marine electrical) as the baseline standard, adapted for vehicular use. This is what Bliss Mobil and Unicat follow.

---

### FINDING #4 — Galvanic Isolation Not Addressed (MEDIUM)

**The issue:** When connected to shore power in different countries, the ground reference can vary. Without galvanic isolation, stray currents can flow between the chassis, the habitat ground, and the shore ground — causing corrosion of the aluminum/steel chassis, tripping GFCIs, or in worst cases, electric shock hazard.

**What production builders do:** Victron makes a Galvanic Isolator (VDI-16, VDI-32, VDI-64) specifically for this. It's a small device (~$100, ~0.5 kg) installed in series with the shore power ground conductor. It blocks low-voltage DC galvanic currents while passing AC fault currents for safety.

**Mitigation:** Add a Victron VDI-32 Galvanic Isolator to the shore power inlet circuit. Trivial cost and weight. Should be mandatory for any rig connecting to international shore power.

---

### FINDING #5 — Battery Thermal Management Not Addressed (MEDIUM)

**The issue:** The Victron NG LFP batteries have a charge temperature range of 5°C to 50°C. Below 5°C, the BMS will block charging. The design doesn't address how the batteries will be kept warm in cold climates (Northern Europe winter, high-altitude camping, Canadian Rockies).

**Why this matters:** If you arrive at camp after a cold drive with depleted batteries and the ambient temperature is below 5°C, the solar and shore charger will be locked out until the batteries warm up. You're stuck with whatever charge you have.

**What production builders do:**

1. **Insulated battery compartment** — The passenger kitchen base should be insulated (25mm closed-cell foam on all sides) to retain heat.
2. **Battery heating pads** — Self-regulating 24V heating pads mounted under each battery, controlled by the BMS temperature sensor. The Victron NG BMS has temperature-based heating output control. ~20W per battery = 80W total when active.
3. **Waste heat recovery** — Route the diesel heater coolant loop near (not through) the battery compartment to provide passive warming.

**Mitigation:** Add battery heating pads (trivial cost, ~$200 total) and insulate the battery compartment. The NG BMS has a dedicated heating relay output for exactly this purpose.

---

### FINDING #6 — No Surge Protection / Lightning Strategy (MEDIUM)

**The issue:** 2050W of rooftop solar panels on a tall expedition vehicle create a significant lightning and surge risk. The design includes no surge protection devices (SPDs) on the solar input, shore input, or DC bus.

**What production builders do:**

1. **Solar SPD** — Type 2 surge arrester on the solar input side of the MPPT (e.g., Victron SPD Kit or Phoenix Contact VAL-SEC-T2). Protects against induced surges from nearby strikes.
2. **Shore power SPD** — Type 2 arrester on the AC input. International shore power quality varies wildly — voltage spikes, transients, and poor grounding are common.
3. **DC bus SPD** — Protects the battery bus from transients.

**Mitigation:** Add SPDs on solar input, shore input, and DC bus. Total cost ~$200–400, weight negligible. Standard practice on marine and expedition electrical systems.

---

### FINDING #7 — 24V→12V Converter is a Single Point of Failure (MEDIUM)

**The issue:** A single Orion 24/12-40 feeds all 12V loads: fridge, fans, water pump, cameras, lighting, heater. If this converter fails, you lose essentially every DC load in the habitat.

**Mitigations:**

| Option | Notes |
|---|---|
| **A. Dual converters** — 2× Orion 24/12-25, one for critical loads (fridge, pump, lighting), one for non-critical (cameras, fans, charging) | True redundancy. If one fails, manually reconnect critical loads to the surviving unit. |
| **B. Carry a spare** | Same approach as the inverter spare. The Orion converters are small and light (~1 kg). |
| **C. Emergency bypass** — Pre-wire a manual switch to connect critical 12V loads directly to a single battery (12.8V tap from one NG battery in the parallel bank, if possible) | Emergency-only. The NG batteries are 25.6V units so this is NOT possible without a separate 12V source. |

**Recommendation:** Option A (dual converters with split loads). Adds ~1 kg and ~$300. A production builder would always do this.

---

### FINDING #8 — Solar Panel Mounting Not Specified (MEDIUM)

**The issue:** The design specifies panel count and layout but not the mounting system. For an expedition vehicle, this is a critical detail. Panels must survive:

- Corrugated road vibration (continuous for hours)
- Tree branch impacts (African bush driving)
- High-speed driving wind loads (130+ km/h)
- Thermal expansion/contraction cycles

**What production builders do:**

1. **Z-bracket or L-bracket mounts** with rubber isolation pads between panel and bracket (vibration dampening).
2. **Through-bolted to roof rails** or structural extrusion — not adhesive-only (VHB tape fails in extreme heat/cold cycling).
3. **Air gap** of 25–50mm between panel and roof for cooling (panel efficiency drops ~0.4%/°C above 25°C).
4. **Sacrificial edge guards** — Aluminum angle around panel perimeter to take branch impacts instead of the glass.

**Mitigation:** Specify the mounting system in the design. Reference the Victron or Renogy expedition mounting kits as a baseline.

---

### FINDING #9 — No Emergency Lighting / Critical Load Priority (LOW-MEDIUM)

**The issue:** The design doesn't define what happens when the battery SOC reaches critical levels (5–10%). In a well-designed expedition system, there's a load-shedding sequence:

1. **First shed:** Non-essential AC loads (TV, charging drawer, vacuum)
2. **Then shed:** Starlink, exterior lighting
3. **Preserve:** Fridge, water pump, interior lighting, cameras, BMS/Cerbo
4. **Last resort:** Emergency LED strip on a separate circuit with its own small fuse — always powered until the BMS disconnects

**What production builders do:**

The Cerbo GX supports programmable relay outputs that can disconnect load groups based on SOC thresholds. Wire the DC distribution so non-critical loads pass through a relay that the Cerbo can open.

Additionally, install a small emergency LED light (battery-backed or on the very last BMS disconnect threshold) in the entry and bathroom areas.

**Mitigation:** Define a load-shedding table and wire the DC distribution with relay-switched groups. The Cerbo GX + Lynx Distributor can implement this in software.

---

### FINDING #10 — Shore Power Cable Storage & Management (LOW)

**The issue:** World travel means carrying multiple shore power cables and adaptors: NEMA 14-50 (NA), NEMA TT-30 (NA campgrounds), CEE17 blue 32A (Europe), CEE17 blue 16A (Europe campgrounds), Indian/Australian/South African adaptors, and extension cables. This is a significant storage requirement that isn't addressed.

**Mitigation:** Designate a specific exterior storage compartment or garage bay for shore power cables and adaptors. Include a cable management system (hook-and-reel or coiled storage) to prevent tangles. Label all cables with their country/standard.

---

## 3. Positive Observations — What's Done Right

These aspects of the design align with or exceed expedition manufacturer standards:

1. **Victron ecosystem throughout.** This is exactly what Unicat and Bliss Mobil use. Global dealer network, consistent software, and proven reliability. Smart choice for international travel.

2. **24V bus voltage.** Industry standard for expedition vehicles in this weight class. Good balance between cable gauge and component availability.

3. **Battery-forward mass balance.** Placing 208 kg of batteries forward of the axle as counterweight is a detail that many DIY builders miss. This shows proper engineering thinking.

4. **Honest autonomy analysis.** The design doesn't fudge the 10-day target — it clearly shows where it falls short and provides realistic scenarios. A production builder would respect this transparency.

5. **Solar array sizing.** 2050W on a habitat this size is excellent — above Unicat and EarthRoamer. Combined with the MPPT 250/100, this is a strong solar system.

6. **Dual DC-DC chargers.** Built-in redundancy for alternator charging. Good practice.

7. **CPAP on native 24V DC.** Small detail but shows attention — avoiding inverter losses on a nightly medical device.

8. **Shore power dual-standard strategy.** The field-switchable MultiPlus-II approach is clever and weight-efficient. Most builders would carry two separate units.

---

## 4. Summary — Priority Action Items

| Priority | Finding | Action | Est. Cost | Est. Weight |
|---|---|---|---|---|
| **CRITICAL** | #1 Generator backup | Add portable diesel generator or engine auto-start | $1,000–4,000 | 21–45 kg |
| **HIGH** | #2 Inverter redundancy | Carry a pre-wired spare MultiPlus-II | $2,500 | 29 kg (stored) |
| **HIGH** | #3 Wiring standards | Adopt ABYC E-11 marine wiring standard throughout | $500–1,000 (premium materials) | ~0 |
| **MEDIUM** | #4 Galvanic isolator | Add Victron VDI-32 | $100 | 0.5 kg |
| **MEDIUM** | #5 Battery thermal | Add heating pads + insulate compartment | $200 | 2 kg |
| **MEDIUM** | #6 Surge protection | Add SPDs on solar, shore, DC bus | $200–400 | ~1 kg |
| **MEDIUM** | #7 12V converter redundancy | Split to 2× Orion converters | $300 | 1 kg |
| **MEDIUM** | #8 Solar mounting | Specify vibration-rated expedition mounting | $500–800 | 5 kg |
| **LOW-MED** | #9 Load shedding | Define SOC thresholds + relay groups | $100 | ~0 |
| **LOW** | #10 Cable storage | Designate shore cable compartment | $0 | 0 |
| | | **TOTAL ADDITIONS** | **$5,400–9,600** | **~59–84 kg** |

---

## 5. Final Assessment

The Gimli2 electrical design is **above average for a DIY expedition build** and competitive with production vehicles on battery capacity and solar. The primary gaps are in **redundancy, construction standards, and backup power** — areas where production builders invest heavily because their warranty and reputation depend on it.

Addressing Findings #1–#5 would bring this design to a level that a Unicat or Bliss Mobil engineer would nod approvingly at. Findings #6–#10 are polish items that separate a good system from a great one.

The Victron ecosystem choice is the single best decision in this design. It means every component talks to every other component, the Cerbo GX provides a unified monitoring and control platform, and Victron dealers exist in nearly every country the rig will visit. This is exactly how the professionals do it.

---

*Review generated 2026-02-28 from expedition vehicle industry benchmarks and publicly available specifications from Unicat, Bliss Mobil, and EarthRoamer.*

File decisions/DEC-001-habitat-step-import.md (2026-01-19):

# Decision: Import Osterath Habitat STEP File

**ID:** DEC-001
**Date:** 2025-01-19
**Status:** FINAL

## Decision Maker

- **Human:** User
- **AI Assistant:** Claude

## Context

The project requires a builder-supplied STEP file as the immutable reference geometry for all interior design work. The Osterath habitat STEP file was received and needed to be imported into the project.

## Options Considered

### Option 1: Import as-is

**Description:** Import the STEP file directly into the reference directory without modification.

**Pros:**
- Maintains exact builder geometry
- No risk of introducing errors
- Clear provenance

**Cons:**
- None identified

### Option 2: Convert to different format

**Description:** Convert STEP to another format (e.g., IGES, Parasolid)

**Pros:**
- Potentially smaller file size
- Compatibility with specific tools

**Cons:**
- Risk of geometry loss
- Loss of provenance
- Unnecessary complexity

## Decision

Import the Osterath Habitat STEP file (`Osterath_Habitat_1225 AF.step`) as-is into the `reference/` directory. This file becomes the immutable source of truth for all interior design work.

## Rationale

The STEP file is the industry-standard format for CAD interchange and maintains full geometric fidelity. Importing as-is preserves the exact builder intent and provides clear traceability.

## Implications

- All interior designs must conform to this geometry
- The STEP file must never be modified (per GOVERNANCE.md)
- Dimensions and features must be extracted and documented in habitat.yml
- WI-002, WI-003, WI-004 are now unblocked and can proceed

## Requirements Addressed

- Foundation for all subsequent design work

## Related Decisions

- None (first decision)

## File Details

- **Filename:** `Osterath_Habitat_1225 AF.step`
- **Size:** 1.4 MB
- **Provider:** Osterath
- **Revision:** 1225 AF
- **Import Date:** 2025-01-19

## Next Steps

1. Open STEP file in Fusion 360
2. Measure interior dimensions
3. Identify windows, doors, and features
4. Populate habitat.yml with extracted data
5. Mark WI-001 as complete

## Notes

This is the foundational decision for the project. All subsequent interior design work depends on this reference geometry.

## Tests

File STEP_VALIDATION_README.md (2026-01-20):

# STEP Validation Readme

## Purpose

This readme summarizes what can be validated **today** against the immutable habitat STEP file and supplier documentation, and what remains pending. It is intended as a lightweight, repeatable checklist for confirming that the STEP geometry, `habitat.yml`, and supplier specs are in sync.

## Inputs Used

- `reference/Osterath_Habitat_1225 AF.step` (immutable STEP reference). 
- `habitat.yml` (documented windows/doors/features and interior dimensions). 
- `reference/supplier-specs/selections.yml` (selected products and key specs). 
- Supplier PDFs stored under `reference/supplier-specs/*` (reference-only; no automated parsing). 

## Method (Current Capability)

1. **Metadata consistency check** between `habitat.yml` and `reference/supplier-specs/selections.yml` for windows/doors. 
2. **Reference inventory** of supplier documents present in `reference/supplier-specs/`. 
3. **Manual-only STEP review requirement**: actual geometry validation (e.g., window cutout positions, sill heights, door swing) still requires CAD tooling (e.g., Fusion 360 interference check noted in `habitat.yml`). 

> Based on the current repository contents, there is **no automated STEP geometry parser or validation script**. Geometry validation must be performed in a CAD tool and the extracted measurements documented in YAML. This assumes no additional tooling exists outside the repo. Please confirm if you have a preferred STEP parsing workflow. 

## Findings

### Supplier Documents Present

- Windows: `reference/supplier-specs/windows/Window-dimensions.pdf` and `Roof-window-dimensions.pdf`. 
- Doors: `reference/supplier-specs/doors/Door-dimensions.pdf`. 

### Consistency Checks (YAML vs. YAML)

**Windows**

| Feature | `habitat.yml` | `selections.yml` | Result |
| --- | --- | --- | --- |
| WIN-01 RA-40 cutout | 670 x 1063 mm | 670 x 1063 mm | ✅ Match |
| WIN-01 visible | 637 x 1027 mm | 637 x 1027 mm | ✅ Match |
| WIN-02 RA-40 cutout | 670 x 1063 mm | 670 x 1063 mm | ✅ Match |
| WIN-02 visible | 637 x 1027 mm | 637 x 1027 mm | ✅ Match |
| WIN-03 DR-20 cutout | 554 x 698 mm | 554 x 698 mm | ✅ Match |
| WIN-03 visible | 400 x 650 mm | 400 x 650 mm | ✅ Match |
| WIN-04 RA-30 cutout | 570 x 673 mm | 570 x 673 mm | ✅ Match |
| WIN-04 visible | 537 x 637 mm | 537 x 637 mm | ✅ Match |

**Door**

| Feature | `habitat.yml` | `selections.yml` | Result |
| --- | --- | --- | --- |
| DOOR-01 opening | 637 x 1027 mm | 637 x 1027 mm | ✅ Match |
| DOOR-01 swing/hinge | outward / right | outward / right | ✅ Match |

### Gaps / Pending Measurements

The following fields are still `null` or marked as pending, which means they need to be extracted from the STEP file (or measured in CAD) and then recorded in YAML:

- Window sill heights (WIN-01, WIN-02, WIN-04). 
- Window positions from wall corners / front wall (WIN-01, WIN-02, WIN-04). 
- Roof window position from front/side (WIN-03). 
- Door threshold height (DOOR-01). 
- Door swing keep-out zones (currently `pending_step_analysis` in `habitat.yml`). 

## Recommended Next Validation Steps (CAD-Based)

1. Open the STEP file in Fusion 360 (or preferred CAD tool). 
2. Measure window/door cutout locations and sill/threshold heights. 
3. Extract window sill heights for WIN-01, WIN-02, and WIN-04 from the STEP file and record them in YAML. 
4. Extract window positions from wall corners/front wall for WIN-01, WIN-02, and WIN-04 and record them in YAML. 
5. Extract roof window position from the front/side walls for WIN-03 and record it in YAML. 
6. Extract door threshold height for DOOR-01 and record it in YAML. 
7. Confirm door swing envelope and document keep-out zone extents. 
8. Update `habitat.yml` and `reference/supplier-specs/selections.yml` with measured positions. 
9. Record findings (and any deviations) as new requirements or decisions, per governance. 

## Proposed Automation (Optional)

If you want automated checks in-repo, we could add:

- A small Python validation script that loads `habitat.yml` and `selections.yml` to detect mismatches. 
- A CI check that fails if critical dimensions diverge. 

This would still not replace CAD validation for STEP geometry but would enforce YAML consistency over time.

## Extraction Script (Experimental)

An experimental script is provided to scan the STEP file for planar faces that match the expected cutout sizes and report candidate positions and sill/threshold heights:

```bash
python scripts/extract_step_openings.py
```

The script requires `cadquery` and `pyyaml` and prints a YAML block with face centers, bounding boxes, and sill/threshold heights for each matched opening. These values still need to be confirmed in CAD before being copied into `habitat.yml` or `reference/supplier-specs/selections.yml`.

For convenience, you can run the wrapper script and capture output to a file:

```bash
scripts/run_step_openings.sh
```

This writes `tmp/step_openings.yaml` by default. Override paths by setting environment variables: `STEP_PATH`, `HABITAT_PATH`, `OUTPUT_PATH`, and `TOLERANCE_MM`.

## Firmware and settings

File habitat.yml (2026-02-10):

# Habitat Reference Definition
# This file defines metadata for the immutable habitat shell geometry

metadata:
  project: Gimli2 Habitat Interior Design
  version: 0.2.0
  created: 2025-01-19
  last_updated: 2025-01-19
  dimensions_verified: 2025-01-19

# Reference Geometry
reference:
  # Location of the immutable STEP file
  step_file: reference/Osterath_Habitat_1225 AF.step

  # Status - this file is NEVER modified directly
  status: immutable

  # Source of the geometry
  source:
    provider: Osterath  # Builder-supplied geometry
    received_date: 2025-01-19
    revision: "1225 AF"

  # Change control
  change_control:
    owner: human  # Only humans can authorize changes
    process: See GOVERNANCE.md for change control protocol
    last_change: 2025-01-19

# Vehicle Configuration
vehicle_configuration:
  drive_side: left   # Left-Hand Drive (LHD)
  driver_side: left  # Left side of vehicle when facing forward = -X axis
  passenger_side: right  # Right side of vehicle when facing forward = +X axis
  notes: |
    Mercedes-Benz 1225 AF is a Left-Hand Drive (LHD) vehicle.
    All "driver side" / "passenger side" references in this project use
    forward-facing orientation:
      Driver   = Left  = -X (in 3D viewer coordinates)
      Passenger = Right = +X (in 3D viewer coordinates)

# Coordinate System
coordinate_system:
  origin: builder_defined  # Origin as defined in STEP file
  units: millimeters
  up_axis: Z
  forward_axis: Y

  # Reference points (to be populated after STEP import)
  reference_points:
    floor_level: null
    ceiling_level: null
    entry_door_center: null
    rear_axle_position_from_interior_rear_wall: 2140.0  # mm (derived from 2200mm external - 60mm wall)

# Habitat Dimensions (measured from STEP file)
dimensions:
  interior_length: 4780  # mm
  interior_width: 2280   # mm
  interior_height: 2160  # mm
  floor_area: 10.90      # m² (4.78 x 2.28)
  volume: 23.54          # m³ (4.78 x 2.28 x 2.16)

# Defined Features
features:
  walls:
    - id: WALL-FRONT
      location: front
      length: 2280  # mm (width of habitat)
    - id: WALL-REAR
      location: rear
      length: 2280  # mm
      features: [WIN-01, WIN-02]  # Two RA-40 windows
    - id: WALL-DRIVER
      location: driver-side
      length: 4780  # mm (length of habitat)
      features: [DOOR-01, WIN-05]  # Entry door and kitchen window
    - id: WALL-PASSENGER
      location: passenger-side
      length: 4780  # mm
      features: [WIN-04]  # Bathroom window

  windows:
    - id: WIN-01
      model: RA-40
      location: rear-driver-side
      wall: WALL-REAR
      opening_width: 637   # mm visible
      opening_height: 1027  # mm visible
      cutout_width: 670    # mm
      cutout_height: 1063  # mm
    - id: WIN-02
      model: RA-40
      location: rear-passenger-side
      wall: WALL-REAR
      opening_width: 637   # mm visible
      opening_height: 1027  # mm visible
      cutout_width: 670    # mm
      cutout_height: 1063  # mm
    - id: WIN-03
      model: DR-20
      location: roof
      opening_width: 400   # mm visible
      opening_height: 650  # mm visible
      cutout_width: 554    # mm (verified from STEP file)
      cutout_height: 698   # mm (verified from STEP file)
      center_mm: [0, 2478, 3615]
    - id: WIN-04
      model: RA-30
      location: passenger-side
      wall: WALL-PASSENGER
      zone: bathroom
      opening_width: 537   # mm visible
      opening_height: 637  # mm visible
      cutout_width: 570    # mm
      cutout_height: 673   # mm
      notes: Horizontal orientation (673mm wide x 570mm tall)
    - id: WIN-05
      model: RA-40
      location: driver-side
      wall: WALL-DRIVER
      zone: kitchen
      opening_width: 637   # mm visible
      opening_height: 1027  # mm visible
      cutout_width: 670    # mm
      cutout_height: 1063  # mm
      notes: Horizontal orientation (1063mm wide x 670mm tall)

  doors:
    - id: DOOR-01
      model: DE-15
      location: driver-side
      wall: WALL-DRIVER
      opening_width: 700   # mm - standard RV entry door
      opening_height: 1800 # mm - full height entry
      cutout_width: 700    # mm
      cutout_height: 1800  # mm
      swing: outward
      hinge_side: right

  hatches:
    - id: HATCH-01
      model: LU-40
      location: garage-shell-driver-side
      wall: WALL-DRIVER
      cutout_width: 600    # mm
      cutout_height: 550   # mm
      notes: Driver side garage access hatch
    - id: HATCH-02
      model: LU-40
      location: garage-shell-passenger-side
      wall: WALL-PASSENGER
      cutout_width: 600    # mm
      cutout_height: 550   # mm
      notes: Passenger side garage access hatch

  mounting_surfaces: []
  fixed_elements: []

# Allowed Operations on Reference Geometry
allowed_operations:
  - read
  - measure
  - reference
  - derive_constraints
  - extract_surfaces_for_mounting
  - generate_keep_out_zones
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

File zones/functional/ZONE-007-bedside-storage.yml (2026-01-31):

# Zone: Bedside Storage Cabinets
# Location: Both sides of lift bed, rear section

id: ZONE-007
name: Bedside Storage Cabinets
type: functional
description: |
  Bedside storage on both sides of the lift bed.
  LOWER NIGHTSTANDS: Sit ON TOP of garage shell (860mm), flush with bed surface (1120mm).
    - 390mm from wall (flush with bed edge)
    - 400mm deep (from window toward rear, positioned between window and hatches)
    - Located at headboard end for phones, AC, cables, charging
  UPPER CABINETS: Above window zone (1435mm to ceiling).
    - Can extend full bed length (2000mm)
    - Clothing/storage

bounds:
  type: dual_boxes
  reference: habitat.yml coordinate system

  # CONSTRAINT ANALYSIS:
  # U-Shell arms: 509mm deep from rear wall
  # Hatches (HATCH-01/02): center at 500mm from rear, 600mm wide → 200-800mm from rear
  #   - Hatches are BELOW U-shell (center_y=430mm), so nightstands on top don't block them
  # Windows (WIN-01/02): center at 1200mm from rear, 1063mm wide → 668-1732mm from rear
  # Bed: 2000mm long from rear wall
  #
  # NIGHTSTAND DESIGN:
  # - Sits ON TOP of U-shell arms (509mm deep)
  # - Rear face: AT rear wall (0mm from rear)
  # - Front face: AT U-shell arm front edge (509mm from rear)
  # - Depth: 509mm (matches U-shell arm)
  # - Sits ON U-shell top (860mm) up to bed surface (1120mm)
  # - Hatches below are not blocked (they're at 155-705mm height)

  driver_side_cabinet:
    position:
      from_driver_wall: 90    # mm - leaves 90mm gap to bed edge
    lower_nightstand:
      width: 300              # mm (cabinet width, away from wall)
      depth: 509              # mm (matches U-shell arm depth)
      height: 260             # mm (shell top 860mm to bed surface 1120mm)
      position_from_rear: 0   # mm (rear face at rear wall)
      height_range: [860, 1120]  # mm (on U-shell arm, flush with bed)
      notes: |
        Nightstand for phones, AC adapter, cables, USB charging.
        Sits on top of U-shell driver arm.
        Hatches below (at 430mm height) are not blocked.
    upper_section:
      width: 300              # mm (cabinet width)
      depth: 2000             # mm (full bed length above window)
      height_range: [1435, 2160]  # mm (above window top to ceiling)
      notes: Full length above window clearance

  passenger_side_cabinet:
    position:
      from_passenger_wall: 90 # mm - same as driver side
    lower_nightstand:
      width: 300              # mm (cabinet width, away from wall)
      depth: 509              # mm (matches U-shell arm depth)
      height: 260             # mm (shell top 860mm to bed surface 1120mm)
      position_from_rear: 0   # mm (rear face at rear wall)
      height_range: [860, 1120]  # mm (on U-shell arm, flush with bed)
      notes: |
        Nightstand for phones, AC adapter, cables, USB charging.
        Sits on top of U-shell passenger arm.
        Hatches below (at 430mm height) are not blocked.
    upper_section:
      width: 300              # mm (cabinet width)
      depth: 2000             # mm (full bed length above window)
      height_range: [1435, 2160]  # mm (above window top to ceiling)
      notes: Full length above window clearance

cabinet_zones:
  # LOWER NIGHTSTANDS (on U-shell arms, at bed level)
  nightstand_zone:
    height_range: [860, 1120]   # mm - on U-shell top to bed surface
    depth: 509                  # mm - matches U-shell arm depth
    position_from_rear: 0       # mm - rear face at rear wall
    use: nightstand             # Phones, AC, cables, USB charging
    access: open_top_or_drawer

  # WINDOW ZONE (no cabinets - keep clear for light)
  window_zone:
    height_range: [765, 1435]   # mm - window vertical span
    depth: n/a                  # mm - NO CABINET in window zone
    use: natural_light          # Keep clear
    access: n/a

  # UPPER CABINETS (above windows)
  upper_zone:
    height_range: [1435, 2160]  # mm - above window top to ceiling
    depth: 2000                 # mm - can extend full bed length
    use: clothing_or_storage    # Hanging or shelved
    access: door

adjacencies:
  required:
    - ZONE-004  # Sleeping - bed between cabinets
    - ZONE-003  # Garage shell - nightstands sit on top
  preferred:
    - ZONE-005  # Living/dinette - can serve as display/storage
  forbidden: []

constraints:
  min_area: 0.70      # m² (2 x 0.3 x 0.4 nightstands + 2 x 0.3 x 2.0 x 0.725 uppers)
  min_dimension: 300  # mm (cabinet width)
  ceiling_height: full
  floor_access: not_needed
  wall_access: required  # Mounting for upper cabinets
  natural_light: not_needed
  ventilation: not_needed
  privacy: none
  noise_level: any

fixed_elements:
  - nightstand_surfaces    # Open top or shallow drawer
  - upper_cabinet_frames
  - upper_cabinet_doors
  - interior_lighting      # LED strips, automatic on door open
  - usb_charging_ports     # At nightstand level both sides
  - cable_management       # Grommets for AC adapters, phone cables
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

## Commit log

2026-01-19 Initial project bootstrap: Gimli2 Habitat Interior Design
    Establishes AI-governed, requirements-driven design framework:
    - GOVERNANCE.md: Source of truth hierarchy, directionality rules
    - AGENTS.md: AI operating guidelines, conflict detection protocol
    - habitat.yml: Immutable reference geometry metadata
    - Kanban workflow with dependency tracking
    - Decision log framework with templates
    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
2026-01-19 Import Osterath Habitat STEP file as immutable reference
    - Added reference/Osterath_Habitat_1225 AF.step (1.4 MB)
    - Updated habitat.yml with file reference and provider metadata
    - Created DEC-001: Decision log for STEP import
    - Updated WI-001 status to in_progress
    Next: Analyze geometry in Fusion 360 and populate dimensions
    [Osterath_Habitat_1225 AF.step]
2026-01-19 Add verified interior dimensions from STEP analysis
    Dimensions measured in Fusion 360:
    - Interior Length: 4780 mm
    - Interior Width: 2280 mm
    - Interior Height: 2160 mm
    - Floor Area: 10.90 m²
    - Volume: 23.54 m³
    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
2026-01-19 Add supplier specs and document windows/doors
    Supplier specifications added:
    - Window-dimensions.pdf (Outbound RA series)
    - Roof-window-dimensions.pdf (Outbound DR series)
    - Door-dimensions.pdf
    Selected products documented in selections.yml:
    - 2x RA-40 rear windows (722x1113mm, 637x1027mm visible)
    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
2026-01-19 Add RA-30 bathroom window on driver side
    - WIN-04: RA-30 bathroom window (537x637mm visible opening)
    - Located on driver side wall
    - Updated selections.yml with full specs
    - Updated habitat.yml features
    Window inventory now complete:
    - 2x RA-40 rear windows
    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
2026-01-20 validated STEP files and created a renderer , resolved the data against the geometry
    [habitat.yml]
2026-01-22 fixed the nigght stand
    [ZONE-004-sleeping.yml, ZONE-007-bedside-storage.yml, habitat.yml]
2026-02-21 made teh decsion for GRP and furniture and cabinet attaching solutrions
